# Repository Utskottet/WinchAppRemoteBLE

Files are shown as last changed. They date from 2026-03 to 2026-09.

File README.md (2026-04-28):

# ParaWinch

Paragliding winch control system. The winch controller communicates with a handheld remote over 868 MHz LoRa. The remote also connects via BLE to a phone app for monitoring and configuration.

**Phone app:** https://utskottet.github.io/parawinch/

## Repository structure

| Folder | Description | Hardware |
|---|---|---|
| `winch/` | Winch controller firmware | M5Stack Core (ESP32) + Waveshare LoRa 868 MHz |
| `remote/` | Handheld remote firmware | Seeed XIAO nRF52840 + Wio SX1262 |
| `sim/` | LoRa simulator — mimics winch transmissions for development without the winch | Seeed XIAO nRF52840 + Wio SX1262 |
| `archive/itsy-bitsy/` | Old test firmware, not in use | Adafruit ItsyBitsy |
| `docs/` | System specifications and notes | — |

## Communication

```
Phone  <── BLE ──>  Remote (Xiao nRF52840)  <── 868 MHz LoRa ──>  Winch (M5Stack ESP32)
```

## Docs

- [Specifications](docs/specifications.md)
- [Upgrade plan](docs/upgrade_plan.md)
- [Force calibration plan](docs/winch_force_calibration_plan.md)
- [Antenna tests](docs/antenna_tests.md)
- [Lisp scripts](docs/lisp.txt)

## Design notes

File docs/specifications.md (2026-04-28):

# Winch System Specifications
# Status: verified measured values only -- no estimates, no future plans

---

## Battery

| Parameter | Value | Source |
|---|---|---|
| Cell configuration | 20S | VESC config + log confirmed |
| Max voltage | 84.0 V | 20S × 4.2 V/cell |
| Nominal voltage | 74.0 V | 20S × 3.7 V/cell |
| Log resting voltage | 76.7 V | 3.835 V/cell (partial charge) |

Note: plan document says 22S -- this is wrong. Use 20S.

---

## Motor

| Parameter | Value | Source |
|---|---|---|
| Model | QS138 90H | plate |
| Serial | SIA72V4000WM11021 | plate |
| Pole pairs | 5 | user count + VESC detection + RPM measurement test confirmed 2026-04-27 |
| Flux linkage λ | 19.844 mWb | VESC motor detection |
| Motor R | 4 mΩ | VESC motor detection |
| Motor L | 35.3 µH | VESC motor detection |
| Kt | 0.1719 Nm/A | derived from λ, pole pairs |
| Kv (line-line peak) | 55.6 rpm/V | derived from λ, pole pairs |
| Kv (ERPM/V) | 277 ERPM/V | derived from λ via Kt (reliable); earlier ~257 value was from low-speed log with RPM controller error -- discard |
| Sensor mode | Hall | VESC config |

---

## Drivetrain

| Parameter | Value | Source |
|---|---|---|
| Drive type | Timing belt (synchronous) | physical |
| Belt | Optibelt Omega 1000-8M-20 | physical |
| Belt pitch | 8M (8 mm)  | physical |
| Belt length | 1000 mm (125 teeth) | physical |
| Belt width | 20 mm | physical |
| Belt material | Rubber, fiberglass cord | datasheet |
| Belt temp range | −30°C to +100°C | datasheet (ISO 9563) |
| Motor pulley | 22T | physical count  |
| Drum pulley | 90T | physical count  |
| Gear ratio | 4.091 | physical count 22T/90T confirmed (22/90 = 4.0909) |

Note: plan document says 4.09 -- that was correct. VESC was configured to 4.180 -- this is wrong, corrected to 4.091.

---

## Drum

| Parameter | Value | Source |
|---|---|---|
| Aluminium flange OD | 315 mm  | measured (structural reference, not used in force model) |
| Full drum diameter (all 1500m wound) | 265 mm | measured |
| Empty drum diameter (all line out) | 120 mm | measured |
| Estimated drum width | ~214 mm | derived from geometry |
| Estimated layers | 29 | derived |
| Turns per layer | ~85 | derived |

---

## Line

| Parameter | Value | Source |
|---|---|---|
| Type | Dyneema SK75 | physical |
| Diameter | 2.5 mm | measured |
| Total length | 1500 m | measured |
| Breaking strength | 740 kg | spec SK75 2.5mm |

---

## VESC

| Parameter | Value | Source / Note |
|---|---|---|
| VESC ID | 56 | from log |
| Wheel diameter (set) | 265 mm | corrected to full drum diameter |
| Gear ratio (set) | 4.091 | corrected from 4.180 |
| Battery cells (set) | 20S | correct |
| Motor current max | 80 A | currently set |
| Absolute max current | 388.7 A | hardware protection, do not change |
| Battery current max | 250 A | ~19 kW peak battery protection |
| ERPM max | 11000 | currently set |
| ERPM min | -11000 | symmetric |
| Current Kp | 0.0353 | VESC detection |
| Current Ki | 3.97 | VESC detection |
| Observer gain | 2.54 | VESC detection |

---

## Force Model

### Theoretical (from Kt, no losses)

```
line_force_kg = (Kt × current_A × gear_ratio) / (drum_radius_m × 9.81)
             = 0.5410 × current_A  (at full drum 265mm, gear ratio 4.091)
```

### Measured calibration (from static crane scale tests, full drum 265mm)

Drivetrain efficiency: 93% with ~4.6 kg constant friction offset.

```
force_kg = 0.503 × current_A − 4.6   (at full drum 265mm)
```

Source: log 2 (20–80A) and log 3 (100–140A), 2026-04-27.

| Current | Theoretical | Measured | Fit | Data quality |
|---|---|---|---|---|
| 20 A | 10.8 kg | 7.0 kg | 5.5 kg | measured |
| 40 A | 21.6 kg | 15.0 kg  | 15.5 kg | measured |
| 50 A | 27.1 kg | 20.0 kg  | 20.6 kg | measured |
| 60 A | 32.5 kg | 25.0 kg  | 25.6 kg | measured |
| 70 A | 37.9 kg | 30.0 kg  | 30.6 kg | measured |
| 80 A | 43.3 kg | 33.0 kg  | 35.7 kg | measured |
| 100 A | 54.1 kg | 50.0 kg  | 45.7 kg | measured |
| 120 A | 64.9 kg | --- | 55.8 kg | UNCERTAIN (43-56 kg range, repeat needed) |
| 140 A | 75.7 kg | 65.0 kg  | 65.8 kg | measured |

### Drum compensation (from measured calibration)

```
force_at_D = force_at_265mm × (265 / D_mm)
```

| Current | Full 265mm | 220mm  | 180mm  | 140mm | Empty 120mm |
|---|---|---|---|---|---|
| 40 A | 15.5 kg | 18.7 kg | 22.9 kg | 29.4 kg | 34.3 kg |
| 60 A | 25.6 kg | 30.8 kg | 37.7 kg | 48.4 kg | 56.5 kg |
| 80 A | 35.7 kg | 42.9 kg | 52.5 kg | 67.5 kg | 78.7 kg |
| 100 A | 45.7 kg | 55.1 kg | 67.3 kg | 86.5 kg | 101 kg |
| 120 A | 55.8 kg | 67.2 kg | 82.1 kg | 106 kg  | 123 kg |
| 140 A | 65.8 kg | 79.3 kg | 96.9 kg | 125 kg  | **145 kg** |

140A at empty drum = 145 kg. Safety factor vs 740 kg line = 5.1:1.

WARNING: In real tow operation the drum STARTS near-empty and fills during the tow.
The empty drum column is therefore the START of the tow, not the end.
Drum compensation is mandatory -- without it, current must be set based on the starting
(smallest) drum diameter to avoid overloading the pilot at the beginning of the tow.

---

## Drum Diameter vs Line-Out Model

Linear approximation (area model):

```
line_on_drum_m = 1500 - line_out_m
drum_radius_m  = sqrt(r_empty^2 + (r_full^2 - r_empty^2) × (line_on_drum / 1500))
drum_diam_mm   = drum_radius_m × 2 × 1000

where:
  r_empty = 0.060 m
  r_full  = 0.1325 m
```

Key points:

| Line out (m) | Line on drum (m) | Est. drum diam (mm) |
|---|---|---|
| 0 | 1500 | 265 |
| 300 | 1200 | 246 |
| 600 | 900 | 226 |
| 900 | 600 | 201 |
| 1200 | 300 | 169 |
| 1380 | 120 | 139 |
| 1500 | 0 | 120 |

---

## Line Speed (current ERPM max = 11000)

Motor mech RPM max = 11000 / 5 = 2200 RPM
Drum RPM max = 2200 / 4.091 = 538 RPM

| Drum state | Diam | Max line speed |
|---|---|---|
| Full (all wound) | 265 mm | 7.47 m/s = 27 km/h  |
| Empty (all out)  | 120 mm | 3.39 m/s = 12 km/h  |

27 km/h is below B class trim speed (~40 km/h). See upgrade_plan.md for ERPM and gear change plans.

Physics ceiling (back-EMF = battery voltage, regardless of ERPM setting):
- At resting 76.7V:  277 × 76.7 / 5 / 4.091 × π × 0.265 / 60 × 3.6 = 52 km/h at full drum
- At full charge 84V: 277 × 84   / 5 / 4.091 × π × 0.265 / 60 × 3.6 = 57 km/h at full drum

---

## Tow Operation Profile

### Direction of operation -- READ THIS FIRST

This is a REELING IN system, like a sailplane winch.

```
BEFORE TOW: line is laid out on the field. Drum is nearly EMPTY.
DURING TOW: winch reels IN the line. Drum FILLS.
AT RELEASE: pilot is airborne. Drum is approximately half full.
```

Typical tow range:
- Start: 1300–1500 m line out (drum 120–148 mm, nearly empty)
- Release: 600–750 m line out (drum 207–219 mm, about half full)

The MOST DANGEROUS moment is the START of the tow:
- Drum is at its smallest → highest force per amp
- Line speed is at its lowest (slow ground run)
- Pilot is on the ground and cannot escape

Safe current limits MUST be calculated from the starting drum diameter.
Setting current based on full drum (265 mm) will severely overload the pilot.

### Tow profile table (current ERPM 11000, 80 kg pilot)

Tow progresses top to bottom (line reeling in, drum filling):

| Phase | Line out | Drum | Max speed | 60 A  | 80 A  | 100 A | Max A (80 kg) |
|---|---|---|---|---|---|---|---|
| START | 1500 m | 120 mm | 12 km/h | 47 kg | 79 kg | **101 kg**| **81 A** |
| | 1400 m | 135 mm | 14 km/h | 42 kg | 70 kg | **90 kg** | **90 A** |
| | 1300 m | 148 mm | 15 km/h | 38 kg | 64 kg | **82 kg** | **98 A** |
| | 1200 m | 160 mm | 16 km/h | 35 kg | 59 kg | 76 kg | 105 A |
| | 1100 m | 171 mm | 17 km/h | 33 kg | 55 kg | 71 kg | 112 A |
| | 1000 m | 182 mm | 18 km/h | 31 kg | 52 kg | 67 kg | 118 A |
| | 900 m | 192 mm | 19 km/h | 30 kg | 49 kg | 63 kg | 124 A |
| | 800 m | 201 mm | 20 km/h | 28 kg | 47 kg | 60 kg | 130 A |
| | 700 m | 210 mm | 21 km/h | 27 kg | 45 kg | 58 kg | 136 A |
| RELEASE | 600 m | 219 mm | 22 km/h | 26 kg | 43 kg | 55 kg | 141 A |

Bold = exceeds 80 kg pilot weight limit at that current.

Force formula: force_at_D = (0.503 × A − 4.6) × (265 / D_mm)
Max safe A:    I_max = (target_kg × D_mm / 265 + 4.6) / 0.503

### Safe current limits by start position (80 kg pilot, force ≤ pilot weight)

| Start position | Drum diam | Max safe current |
|---|---|---|
| 1500 m out | 120 mm | 81 A |
| 1400 m out | 135 mm | 90 A |
| 1300 m out | 148 mm | 98 A |
| 1200 m out | 160 mm | 105 A |
| 1000 m out | 182 mm | 118 A |

As the tow progresses and the drum fills, the same current delivers progressively LESS force.
A tow started at 95 A from 1300 m delivers ~79 kg at the start and only ~55 kg at 600 m release.
This is the correct safe direction -- tension reduces as speed and altitude build.

### Why drum compensation matters

Without compensation, the operator must choose one fixed current for the whole tow.
That current is limited by the start condition (smallest drum = highest force).
With drum compensation in Lisp, current can be increased as the drum fills to maintain
a roughly constant force throughout the tow, allowing stronger pulls at mid-tow
without overloading the pilot at the start.

---

## Safety Analysis

### Line breaking strength vs motor current

Dyneema SK75 2.5mm breaks at 740 kg.

| Safety factor | Max working load | Current needed at full drum |
|---|---|---|
| 3:1 | 247 kg | 446 A |
| 4:1 | 185 kg | 335 A |
| 5:1 | 148 kg | 268 A |

The line will not break from motor force at any realistic operating current.
The risk is pilot overload, not line break.

### Current safety at VESC motor max (80 A)

| Drum state | Line pull | Safety factor vs line break |
|---|---|---|
| Full 265mm | 44 kg | 16.7:1 |
| Empty 120mm | 98 kg | 7.6:1 |

### Pilot load limits

Safe tow force for paraglider launch is typically 50-100% of pilot all-up weight.
This system is set up for 80 kg all-up pilot weight (body + harness + gear).
Max tow force target: 80 kg (= pilot weight).

Safe current at tow start depends on how much line is out -- see Tow Operation Profile above.
Do NOT use the full-drum force numbers to set operating current for real tows.

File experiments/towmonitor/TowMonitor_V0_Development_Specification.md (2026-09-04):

# TowMonitor V0
## Development & Prototype Specification

**Revision:** 0.1  
**Date:** 18 August 2026  
**Status:** Prototype definition / parts selected  

## 1. Purpose

TowMonitor V0 is a compact battery-powered sensor package for development of the next-generation paraglider tow system.

The unit combines tow-force measurement with flight-state sensing in one nRF52840-based node.

### Primary measurements

- Tow-line tension
- Airspeed
- Barometric altitude
- Vertical speed / vario
- Acceleration
- Angular motion / orientation

### Communications

- **V0:** Bluetooth Low Energy
- **Later:** 868 MHz LoRa using an SX1262 module

---

## 2. System Architecture

```text
WH-C100 load cell
      |
      v
Adafruit NAU7802
      |
      +------------------+
                         |
Adafruit BMP581 ---------+---- I2C ---- XIAO nRF52840 Sense
                         |
Sensirion SDP810 --------+
      |
      v
Pitot / static tubing

XIAO nRF52840 Sense
  |- nRF52840
  |- BLE
  |- onboard 6-axis IMU
  |- USB-C
  `- 1S LiPo charging
```

External digital sensors share:

```text
3V3
GND
SDA
SCL
```

The load-cell bridge connects locally to the NAU7802.

---

## 3. Selected Hardware

| Function | Selected part | Interface | Prototype form | Status |
|---|---|---|---|---|
| MCU / BLE | Seeed XIAO nRF52840 Sense | I2C / BLE / GPIO | Development board | Selected |
| IMU | Onboard XIAO 6-axis IMU | Internal | Integrated | Selected |
| Force sensor | WH-C100 150 kg internal load cell | 4-wire bridge | Bare extracted cell | Selected / characterize |
| Load-cell ADC | Adafruit NAU7802 STEMMA QT | I2C | Breakout + screw terminal | Selected |
| Vario / altitude | Adafruit BMP581 STEMMA QT | I2C | Breakout | Selected |
| Airspeed | Sensirion SDP810-500Pa | I2C | Through-hole sensor | Selected |
| Pitot plumbing | Pitot/static probe + silicone tube | Pressure | External | To select |
| Battery | Protected 1S LiPo ~500 mAh | Battery | Pouch cell | Target |
| Long-range radio | SX1262 868 MHz module | SPI | Module | Deferred |

---

## 4. Component Notes

### 4.1 XIAO nRF52840 Sense

Selected as the main controller because it combines:

- nRF52840 MCU
- BLE
- onboard 6-axis IMU
- USB-C
- LiPo charging
- enough GPIO for later SX1262 LoRa

The three external digital sensors all share the same I2C bus, so the sensor package uses very few MCU pins.

### 4.2 WH-C100 Load Cell + NAU7802

The lightweight load cell is extracted from a WH-C100 150 kg hanging scale.

Prototype work:

1. Identify the four bridge wires.
2. Connect to NAU7802.
3. Determine zero offset.
4. Calibrate against known loads.
5. Measure repeatability and creep.
6. Verify dynamic response.
7. Check temperature drift.

Mechanical mounting must load the cell in its intended axis without significant bending or side-loading.

### 4.3 BMP581 Vario / Altitude

The Adafruit BMP581 breakout is selected for easy STEMMA QT / Qwiic wiring.

Firmware will calculate:

- pressure
- altitude
- filtered vertical speed

The sensor should sample static ambient pressure and must be protected from direct ram airflow.

### 4.4 SDP810-500Pa Airspeed Sensor

Selected instead of the tiny SDP31 for the prototype because the SDP810 has mechanically useful tube connections while retaining high sensitivity at low differential pressure.

Key characteristics:

- differential pressure range: **±500 Pa**
- digital I2C interface
- proper tubing connections
- through-hole mounting
- suitable for pitot/static airspeed measurement

Connection:

```text
Pitot total pressure ---- SDP810 high-pressure port
Static pressure --------- SDP810 low-pressure port
```

Use short flexible silicone tubes and provide strain relief.

---

## 5. Electrical Prototype

V0 should be hand-wired on a small perfboard or carrier plate.

### Shared I2C bus

```text
XIAO 3V3 ----+---- NAU7802
             +---- BMP581
             `---- SDP810

XIAO GND ----+---- NAU7802
             +---- BMP581
             `---- SDP810

XIAO SDA ----+---- NAU7802
             +---- BMP581
             `---- SDP810

XIAO SCL ----+---- NAU7802
             +---- BMP581
             `---- SDP810
```

The NAU7802 and BMP581 can use STEMMA QT cables.

The SDP810 can simply use four soldered wires:

- VDD
- GND
- SDA
- SCL

### Battery

Target prototype battery:

**Protected 1S LiPo, approximately 500 mAh**

Charge through the XIAO USB-C interface.

---

## 6. Firmware Data Model

Minimum V0 telemetry:

```text
force_N
force_kgf

differential_pressure_Pa
airspeed_mps

barometric_pressure_Pa
altitude_m
vario_mps

accelerometer_x
accelerometer_y
accelerometer_z

gyro_x
gyro_y
gyro_z

battery_voltage

sensor_status
fault_flags
```

All sensor values should be timestamped so force, airspeed, vario and IMU data can later be correlated.

---

## 7. Prototype Development Sequence

### V0.1 — Bench assembly

Connect:

- XIAO
- NAU7802
- BMP581
- SDP810
- LiPo

Confirm all I2C devices operate together.

### V0.2 — Load-cell characterization

- Extract WH-C100 load cell
- identify bridge wiring
- tare
- calibrate against known loads
- test repeatability and dynamic response

### V0.3 — Vario

Implement:

- pressure acquisition
- pressure filtering
- altitude calculation
- vertical-speed calculation

### V0.4 — Airspeed

Install pitot/static probe and tubing.

Implement:

- differential pressure zeroing
- pressure filtering
- airspeed calculation
- calibration against a known/reference speed

### V0.5 — Combined telemetry

Combine and timestamp:

- force
- airspeed
- altitude
- vario
- IMU
- battery voltage

Send over BLE.

### V0.6 — Mechanical packaging

Provide:

- tube strain relief
- static-pressure protection
- load-cell mechanical alignment
- battery retention
- sensor enclosure

### V0.7 — Tow / flight testing

Compare recorded data against expected tow behaviour and tune filtering.

### V1 — Custom PCB

Only after V0 works reliably:

- integrate bare sensor ICs where useful
- reduce wiring
- add SX1262 868 MHz LoRa
- optimize battery monitoring
- optimize enclosure and connectors

---

## 8. Deferred / Open Items

- Exact pitot/static probe geometry
- Exact silicone-tube dimensions
- Exact LiPo capacity
- LoRa module and antenna implementation
- Final enclosure
- Whether NAU7802 and BMP581 remain as modules or become bare ICs on V1 PCB
- Characterization of the WH-C100 internal load cell

---

## 9. V0 Summary

The intended first prototype is:

```text
XIAO nRF52840 Sense
+
Adafruit NAU7802
+
WH-C100 load cell
+
Adafruit BMP581
+
Sensirion SDP810-500Pa
+
pitot/static probe
+
1S ~500 mAh LiPo
```

This gives one compact sensor node measuring:

**tow force + airspeed + altitude + vario + acceleration + angular motion**

without requiring a custom PCB for the first development version.

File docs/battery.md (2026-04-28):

# ParaWinch Battery Pack

## Overview

| Parameter | Value |
|---|---|
| Configuration | 20s8p (4 modules × 10s, 8 cells per group) |
| Total cells | 160 (40 per module) |
| Cell | LG INR18650 MH1 |
| Nominal voltage | 72V (3.6V × 20) |
| Max charge voltage | 84V (4.2V × 20) |
| Nominal capacity | 25.6 Ah (3200mAh × 8p) |
| Nominal energy | ~1844 Wh |
| Max continuous discharge | 80A (10A × 8p) |
| Charger | 84V 10A |

## Cell Specifications — LG INR18650 MH1

| Parameter | Value |
|---|---|
| Chemistry | INR (Li-NiMnCo) |
| Nominal capacity | 3200 mAh (min 3100 mAh) |
| Nominal voltage | 3.67V |
| Max charge voltage | 4.20V ± 0.05V |
| Cutoff voltage | 2.5V |
| Standard charge | CC 0.5C (1550 mA) / CV 4.2V / cutoff 50 mA |
| Max charge current | 1C (3100 mA) |
| Max discharge current | 10A continuous |
| Size | ø18.4 × 65.1 mm |
| Weight | 49 g |
| Datasheet | LG PS-CY-INR18650MH1 |

Compatible replacement: LG INR18650 MJ1 (3500 mAh, 10A) — same form factor, slightly higher capacity.

## Pack Structure

Four modules connected in series. Each module is 10s with 8 cells per series group (8p). Total: 20s8p, 160 cells.

```
[Module 1] — [Module 2] — [Module 3] — [Module 4]
  10s×8p       10s×8p       10s×8p       10s×8p
  40 cells     40 cells     40 cells     40 cells
```

Each module has balance taps at every series group. Nickel strip welded, 0.3 mm strip on series connections, 0.15 mm acceptable for parallel connections within groups.

### Module 3 — Cell Group Layout

Tap numbers visible on pack:
- Top side: + − 2 4 6 8
- Bottom side: 1 3 5 7 9

Series groups numbered 1–10 from − to +. Each group is 8p (4 cells visible on top side, 4 on bottom side). Adjacent groups share nickel strips at the series boundary.

## BMS

### Hardware
- Ant BMS 10S-24S, Double PCBA variant
- Product page: https://antbms.vip/product/ant-bms-10s-24s-50a-180a-smart-32v-88v-lifepo4-li-ion-lto-battery-protection-board-double-pcba/
- Balance method: Passive, 100 mA
- Balance connector: 21 wires (B0–B20), JST-type connector
- Current sense shunt range: 440A
- Bluetooth built-in (Android/iOS app)
- App: "ANT BMS" — tabs: State, Parameter, Set, BMS Control, Mine
- Admin password: unknown (default passwords 123456/000000/888888/666666 did not work)

### Operating Mode
- Charge-only configuration — BMS does not disconnect on discharge
- Discharge path bypasses BMS entirely — no undervoltage protection during discharge

### Configured Settings (2026-04-28)

| Setting | Value | Notes |
|---|---|---|
| Battery type | Li-ion | |
| Cell count | 20s | |
| Pack capacity | 26 Ah | 8p × 3.2Ah |
| Unit overvoltage protection | 4.20V | Cuts charge |
| Unit overvoltage recovery | 4.15V | Resumes charge |
| Lv2 unit overvoltage protection | 4.30V | Emergency backup |
| Lv2 unit overvoltage recovery | 4.20V | |
| Total overvoltage protection | 84.0V | Was 103V default! |
| Unit diff protection | 1.0V | Temporarily raised from 0.03V to clear fault — set back to 0.03V once cells balanced |
| Unit diff recovery | 0.020V | |
| Balance start voltage | 4.05V | |
| Charge unit balance start voltage | 4.05V | Was 4.10V default |
| Unit diff on voltage | 0.020V | |
| Charge overcurrent protection | 15A | Charger is 10A |
| Charge high temp protection | 45°C | Per MH1 datasheet |
| Charge high temp recovery | 40°C | |
| MOSFET high temp protection | 75°C | Default, leave as is |

### BMS Limitations Discovered

- Passive balance at 100 mA cannot close large voltage gaps (>200 mV) without overheating the balance circuit (reached 59°C)
- BMS latches "unit diff protection" fault when cell difference exceeds threshold — does not auto-clear on parameter change, requires power cycle or clearing protection log
- "Balance limit" warning blocks balancing when gap is too large — BMS treats it as fault, not a condition to fix
- In charge-only mode, balancing may only activate when charger is connected
- To clear stuck fault: use "clear protect time" in BMS Control tab, or power cycle BMS
- Factory default settings are dangerously permissive (total OVP at 103V, unit diff at 1V, charge OC at 50A)

## Protection & Power Path

- 500A KILOVAC LEV200 contactor
- Precharge: 100Ω 25W resistor (permanent passive snubber)
- 300A ANL fuse
- QS10 connectors

## Incident Log

### 2026-04-28 — Module 3 Group 10 Failure (Overcharge)

**Root cause:** Module 4 positive power lead was disconnected (missed during previous maintenance). BMS balance leads for all 20s were still connected. Charger pushed 20s charge voltage (84V) through only 15 series groups (modules 1+2+3). This resulted in approximately 5.6V per cell — far above the 4.2V maximum.

**Failure:** 4 of 8 cells in group 10 of module 3 (between tap 9 and + terminal) were destroyed. All 4 dead cells read 0V — internal short from severe overcharge. The remaining 4 cells in the group survived but were pulled to a lower voltage (~3.5V) by the dead cells.

**Diagnosis steps:**
1. Full pack + to − read 0V
2. Modules 1, 2, 4 verified healthy
3. Module 3: groups 1–9 all reading 4.0V per group (36V total from − to 9)
4. Group 10 (9 to +): 0V
5. Removed nickel strip on + side of group 10
6. All 4 cells in the dead half read 0V — confirmed destroyed

**Repair:**
- Replaced 4 dead cells with new LG INR18650 MH1 (sourced from Electrokit, 54 SEK/cell)
- New cells arrived at ~3.6–3.7V storage voltage
- Old 0.3 mm nickel strip reused for series connection to group 9
- New 0.15 mm nickel strip for parallel connections within the replacement group
- Spot weld settings: 9 ms pulse at 7.5V for 0.3 mm strip, 7 ms for 0.15 mm strip

**Post-repair state:**
- 19 groups at ~4.07V, group 10 at ~3.65V (average of 4 new cells at ~3.6V + 4 surviving cells at ~3.5V)
- BMS entered "unit diff protection" fault due to 400 mV gap
- BMS refused to charge or balance — fault latched
- Balance circuit overheated (59°C) attempting to close gap at 100 mA passive
- Resolution: external bench PSU charge of group 10 through balance connector pins (B19 and B20), 4.0V / 300 mA until group reaches ~3.9–4.0V, then BMS can handle remaining balance

**Key correction:** Pack is 20s8p (not 20s4p as initially assumed). Each group has 8 cells, not 4. The 4 replaced cells are paralleled with 4 surviving cells in group 10.

### Pre-Charge Safety Checklist

Before every charge:
- [ ] Physically verify all 4 module positive power leads are connected (tug test)
- [ ] Measure each module voltage across power terminals (not balance leads) — each should read ~40V
- [ ] Measure full string voltage across main power terminals — should be ~72–84V depending on SOC
- [ ] If full string reads ~60V (15s), a module power lead is disconnected — do not charge
- [ ] Check BMS app State tab — all 20 cells should show voltage, no fault flags

**Important:** Measuring full string voltage alone is NOT sufficient — BMS balance leads can show voltage from cells even when the power path is disconnected. Always verify power lead connections physically or measure across individual module power terminals.

### Post-Incident TODO

- [ ] External bench PSU charge group 10 to ~4.0V via balance pins B19/B20
- [ ] Reconnect BMS and verify fault clears
- [ ] Set unit diff protect back to 0.03V once cells balanced
- [ ] First full charge: monitor cell temps and BMS balance status
- [ ] Capacity test module 3 vs modules 1/2/4 — overcharged groups may have reduced cycle life
- [ ] Consider ordering 4 more MH1 cells as spares

## Supplier Notes

| Part | Source | Notes |
|---|---|---|
| LG INR18650 MH1 | Electrokit (SE) | 54 SEK incl. VAT, in stock |
| LG INR18650 MH1 | Nkon.nl | Alternative, fast EU shipping |
| 0.15 mm nickel strip | — | Sufficient for 8p at 10A/cell |
| 0.3 mm nickel strip | — | Use for series connections, harder to spot weld (needs 9ms+) |
| Ant BMS 10S-24S | antbms.vip | $59–90 USD depending on current rating |

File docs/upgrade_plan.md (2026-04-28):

# Winch Upgrade Plan
# Status: planning only -- nothing here is implemented on the real system

All numbers in this document are derived from real calibration data in specifications.md
but applied to configurations that do not yet exist on the machine.

---

## Open Items

### Completed 2026-04-27
- [x] Crane scale static pull test -- log 2 (20-80A) and log 3 (20-140A) done
- [x] Correct VESC wheel diameter from 280 mm to 265 mm
- [x] Correct VESC gear ratio from 4.180 to 4.091
- [x] VESC motor current max / abs max / battery max confirmed
- [x] VESC ERPM max / min confirmed
- [x] Confirm gear ratio -- 22T/90T = 4.091 physically counted and verified by RPM test
- [x] Confirm pole pairs = 5 by RPM measurement test
- [x] Confirm Kv = 277 ERPM/V from flux linkage (reliable); discarded noisy 257 value

### Still open -- current hardware
- [ ] Repeat 120A crane scale test (43-56 kg range too wide, not reliable)
- [ ] Verify actual drum width (estimated 214 mm)
- [ ] Confirm line-out tracking method (VESC get-dist or encoder)
- [ ] Add MOSFET temp telemetry logging during real tows
- [ ] Implement drum diameter compensation in Lisp using line-out estimate -- HIGH PRIORITY:
      without compensation, fixed current significantly overloads pilot at tow start vs mid-tow

### Drum spacer (current gear, immediate improvement) -- IN PROGRESS
- [ ] 3D print cylindrical spacer: 120 mm bore → 185 mm OD
- [ ] Verify full drum still fits within flange (new full = 300 mm, flange OD = 315 mm -- 7.5 mm margin)
- [ ] Re-wind full 1500 m line onto drum with spacer installed
- [ ] Re-confirm full drum diameter measurement after winding (expect ~300 mm)
- [ ] Raise ERPM to 18000 after spacer is installed (do not raise on bare 120 mm drum)

### Live tow logging -- after spacer install
- [ ] Log real tows: ERPM, motor current, battery voltage, MOSFET temp, duty cycle
- [ ] Log speed and height (GPS or barometric)
- [ ] Verify estimated drum diameter matches line-out model
- [ ] Check MOSFET temps under sustained load -- add temp logging if not already active
- [ ] Use logs to validate or correct force model before implementing Lisp compensation

### Gear change for B class towing
- [ ] Laser-cut 50T drum pulley (8M pitch, ≥20mm wide, PC layers)
- [ ] Source replacement belt Optibelt Omega 840-8M-20 (105T)
- [ ] Fit 50T drum pulley, shift motor mount ~12mm, update VESC gear ratio to 2.273
- [ ] Re-calibrate force model with crane scale at 2.27:1 -- mandatory before any tows
- [ ] Raise VESC motor current max to ≥160A; verify MOSFET thermals in static tests first
- [ ] Set ERPM max ~20,000 for 2.27:1 ratio
- [ ] No-load ERPM test after gear change to verify Kv = 277 ERPM/V at new ratio

---

## ERPM Upgrade: 11000 → 18000 (current gear, B class prep)

At current gear ratio 4.091:1, raising ERPM to 18000 gives:

Motor mech RPM max = 18000 / 5 = 3600 RPM
Drum RPM max = 3600 / 4.091 = 880 RPM

| Drum state | Diam | Max line speed |
|---|---|---|
| Full (all wound) | 265 mm | 12.22 m/s = 44 km/h |
| Empty (all out)  | 120 mm |  5.53 m/s = 20 km/h |

Back-EMF at 18000 ERPM = 18000 / 277 = 65.0 V
Voltage headroom at resting 76.7 V = 11.7 V
Voltage headroom at full charge 84 V = 19 V

Still insufficient for B class at tow start (120mm drum, 20 km/h max) -- see gear change below.
Useful as interim improvement for shorter line starts (≥600m out) or A class gliders.

Tow profile at ERPM 18000, current gear 4.091:1, 80 kg pilot:

| Phase | Line out | Drum | Max speed | 60 A  | 80 A  | 100 A | Max A (80 kg) |
|---|---|---|---|---|---|---|---|
| START | 1500 m | 120 mm | 20 km/h | 47 kg | 79 kg | **101 kg**| **81 A** |
| | 1400 m | 135 mm | 22 km/h | 42 kg | 70 kg | **90 kg** | **90 A** |
| | 1300 m | 148 mm | 25 km/h | 38 kg | 64 kg | **82 kg** | **98 A** |
| | 1200 m | 160 mm | 27 km/h | 35 kg | 59 kg | 76 kg | 105 A |
| | 1100 m | 171 mm | 28 km/h | 33 kg | 55 kg | 71 kg | 112 A |
| | 1000 m | 182 mm | 30 km/h | 31 kg | 52 kg | 67 kg | 118 A |
| | 900 m | 192 mm | 32 km/h | 30 kg | 49 kg | 63 kg | 124 A |
| | 800 m | 201 mm | 33 km/h | 28 kg | 47 kg | 60 kg | 130 A |
| | 700 m | 210 mm | 35 km/h | 27 kg | 45 kg | 58 kg | 136 A |
| RELEASE | 600 m | 219 mm | 36 km/h | 26 kg | 43 kg | 55 kg | 141 A |

Force formula (unchanged from calibration): force_at_D = (0.503 × A − 4.6) × (265 / D_mm)

---

## Gear Change: 90T → 50T Drum Pulley (B Class Towing)

### Why the current gear is insufficient

At 4.091:1 and full charge 84V, physics ceiling at 1300m out (148mm drum):
```
Max ERPM (physics) = 277 × 84 = 23,268
Drum RPM = 23,268 / 5 / 4.091 = 1,138 RPM
Max speed = π × 0.148 × 1,138 / 60 = 8.84 m/s = 31.8 km/h
```
B class trim speed ≈ 40 km/h. 31.8 km/h is the absolute ceiling -- no ERPM setting can overcome this.

### Why flux weakening is not viable

VESC flux weakening currently disabled (field weakening current = 0A).
For 35% speed gain to reach ~43 km/h at 1300m out:
```
id = (19.844e-3 − 19.844e-3/1.35) / 35.3e-6 = 146 A d-axis
```
146A d-axis (heating only, no torque) is not practical. Motor and MOSFET would overheat.

### Tooth count analysis -- why 50T drum pulley

Back-EMF to reach 40 km/h at 120mm drum = 2872 / T_motor × (T_drum/90) volts.
With fixed 22T motor pulley, varying drum pulley:

```
| Drum teeth | Ratio  | Max speed 84V | Max speed 77V | I for 80kg start | 40 km/h? |
|------------|--------|---------------|---------------|------------------|----------|
| 90T (now)  | 4.09:1 | 26 km/h       | 24 km/h       |  81 A            | NO       |
| 60T        | 2.73:1 | 35 km/h       | 32 km/h       | 107 A            | NO       |
| 56T        | 2.55:1 | 37 km/h       | 34 km/h       | 114 A            | NO       |
| 50T        | 2.27:1 | 46 km/h       | 42 km/h       | 139 A            | YES      |
| 44T        | 2.00:1 | 52 km/h       | 48 km/h       | 158 A            | YES      |
```

50T is the recommended choice:
- Achieves 40+ km/h at 120mm drum on both full and resting charge
- 139A for 80 kg at tow start -- within VESC 100/250 capability
- 44T gives unnecessary speed at the cost of ~20A more current

### Practical implementation

**Drum pulley:** 50T, 8M pitch, ≥20mm wide, laser-cut PC layers (same method as current 90T).
Pitch diameter = 50 × 8 / π = 127.3mm (vs current 229.2mm).

**Belt:** smaller drum pulley requires shorter belt.
At current center distance ~262mm, belt length needed ≈ 816mm.
Use **Optibelt Omega 840-8M-20** (105T, 840mm).
Motor mount shifts ~12mm further from drum to tension correctly.

**VESC settings after change:**
- Gear ratio: 2.273 (50/22)
- ERPM max: ~20,000 (gives 40 km/h at 120mm drum, ~74 km/h at full 265mm drum -- but drum
  compensation in Lisp should limit actual speed at larger diameters)
- Motor current max: raise to ≥160A after static crane scale verification

### Estimated force model at 2.27:1

NOT measured. Extrapolated from 4.091:1 calibration assuming same efficiency and proportional friction.

```
Theoretical:       force_kg = 0.301 × A   (at full drum 265mm)
Estimated measured force_kg ≈ 0.280 × A − 2.56
```

**Re-calibrate with crane scale before any tows. Do not use these numbers operationally.**

Safe motor current for 80 kg pilot at tow start (120mm drum, estimated):
```
I ≈ 139 A
```
Raise VESC motor current max to ≥160A for margin. Verify MOSFET thermals in static tests.

---

## Drum Spacer: 120 mm → 185 mm Empty Drum (current gear 4.091:1)

### Why a spacer helps

Without spacer: empty drum = 120 mm, full drum = 265 mm.
Force and speed both vary 2.21× across the tow range.
Max safe current at tow start (120 mm drum, 80 kg pilot) = 81 A -- very low.

Adding a cylindrical spacer to the drum core raises the empty diameter.
If full drum is allowed to grow to 300 mm (flange OD = 315 mm, 7.5 mm margin), the same 1500 m
of line fits in the new annulus by conservation of cross-section area:

```
New annulus area = old annulus area
r_full_new² − r_empty_new² = r_full_old² − r_empty_old²
150² − r_empty_new² = 132.5² − 60²
r_empty_new = sqrt(22500 − 13956) = sqrt(8544) = 92.4 mm
→ D_empty_new = 185 mm
```

### Tow profile with spacer, ERPM 18000, 80 kg pilot

Drum diameter model (area model):
```
drum_radius_mm = sqrt(8543 + 13957 × line_on_drum_m / 1500)
```

| Phase | Line out | Drum | Max speed | 60 A  | 80 A  | 100 A | 120 A | Max A (80 kg) |
|---|---|---|---|---|---|---|---|---|
| START | 1500 m | 185 mm | 30.7 km/h | 37 kg | 51 kg | 65 kg | **80 kg** | **120 A** |
| | 1400 m | 195 mm | 32.3 km/h | 35 kg | 48 kg | 62 kg | 76 kg | 126 A |
| | 1300 m | 204 mm | 33.8 km/h | 33 kg | 46 kg | 59 kg | 72 kg | 132 A |
| | 1200 m | 213 mm | 35.3 km/h | 32 kg | 44 kg | 57 kg | 69 kg | 137 A |
| | 1100 m | 222 mm | 36.7 km/h | 31 kg | 43 kg | 55 kg | 67 kg | 142 A |
| | 1000 m | 230 mm | 38.1 km/h | 29 kg | 41 kg | 53 kg | 64 kg | 147 A |
| | 900 m | 238 mm | 39.4 km/h | 28 kg | 40 kg | 51 kg | 62 kg | 152 A |
| | 800 m | 245 mm | 40.7 km/h | 28 kg | 39 kg | 50 kg | 60 kg | 156 A |
| | 700 m | 253 mm | 42.0 km/h | 27 kg | 37 kg | 48 kg | 58 kg | 161 A |
| RELEASE | 600 m | 260 mm | 43.1 km/h | 26 kg | 36 kg | 47 kg | 57 kg | 165 A |

Force formula (unchanged): `force_at_D = (0.503 × A − 4.6) × (265 / D_mm)`

Physics ceiling at tow start (185 mm drum):
- At resting 76.7V: 277 × 76.7 / 5 / 4.091 × π × 0.185 / 60 × 3.6 = **36.2 km/h**
- At full charge 84V: 277 × 84   / 5 / 4.091 × π × 0.185 / 60 × 3.6 = **39.7 km/h**

ERPM 18000 gives 30.7 km/h at tow start -- below the physics ceiling, so ERPM is the binding limit
throughout the entire tow. Raising ERPM further (up to ~23,000 at 84V) would give more start speed.

### Comparison: without vs with spacer

| Metric | No spacer (120 mm) | Spacer (185 mm) |
|---|---|---|
| Start speed at ERPM 18000 | 20 km/h | 30.7 km/h |
| Physics ceiling at start (84V) | 26 km/h | 39.7 km/h |
| Max safe current at start (80 kg)| 81 A | 120 A |
| Force variation start→600m rel.  | 1.83× | 1.40× |

---

## Speed Ceiling Reference (current gear 4.091:1, all conditions)

```
| Battery   | Physics ceiling ERPM | Max speed full drum | Max speed 120mm drum |
|-----------|----------------------|---------------------|----------------------|
| 84V full  | 23,268               | 57 km/h             | 26 km/h              |
| 76.7V rest| 21,236               | 52 km/h             | 24 km/h              |
```

Setting ERPM above these values has no effect -- motor back-EMF prevents higher speed.

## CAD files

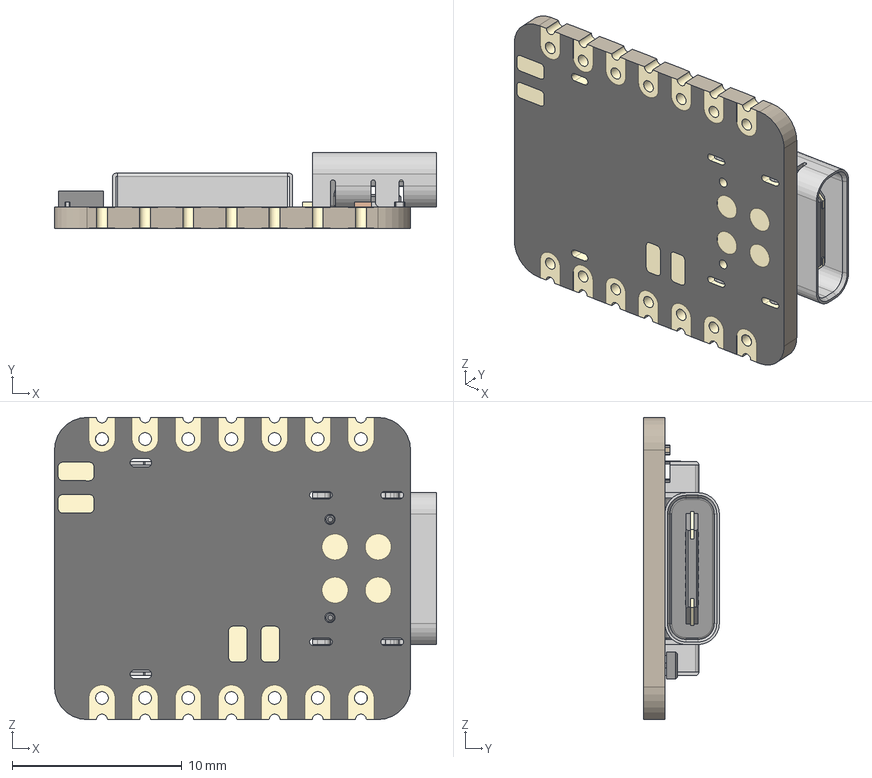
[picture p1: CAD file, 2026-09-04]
experiments/Fork Ikoka Nano/3dmodels/XIAO-nRF52840 v15.step
22.5 x 4.46 x 17.8 mm
BOSS-EXTRUDE14_8_
BOSS-EXTRUDE7_4_
BOSS-EXTRUDE7_3_
BOSS-EXTRUDE14_4_
BOSS-EXTRUDE14_2_
BOSS-EXTRUDE14_11_
BOSS-EXTRUDE7_7_
BOSS-EXTRUDE14_9_
BOSS-EXTRUDE14_3_
BOSS-EXTRUDE14_7_
MIRROR2
BOSS-EXTRUDE14_5_
BOSS-EXTRUDE14_12_
BOSS-EXTRUDE7_8_
BOSS-EXTRUDE7_1_
BOSS-EXTRUDE14_10_
BOSS-EXTRUDE7_9_
BOSS-EXTRUDE14_6_
BOSS-EXTRUDE14_1_
BOSS-EXTRUDE7_6_
BOSS-EXTRUDE7_2_
CUT-EXTRUDE5
BOSS-EXTRUDE7_5_
Shield
Pins
CAP x 2
ANT1
Silkscreen
CAP 3
LED
USR
2 v1

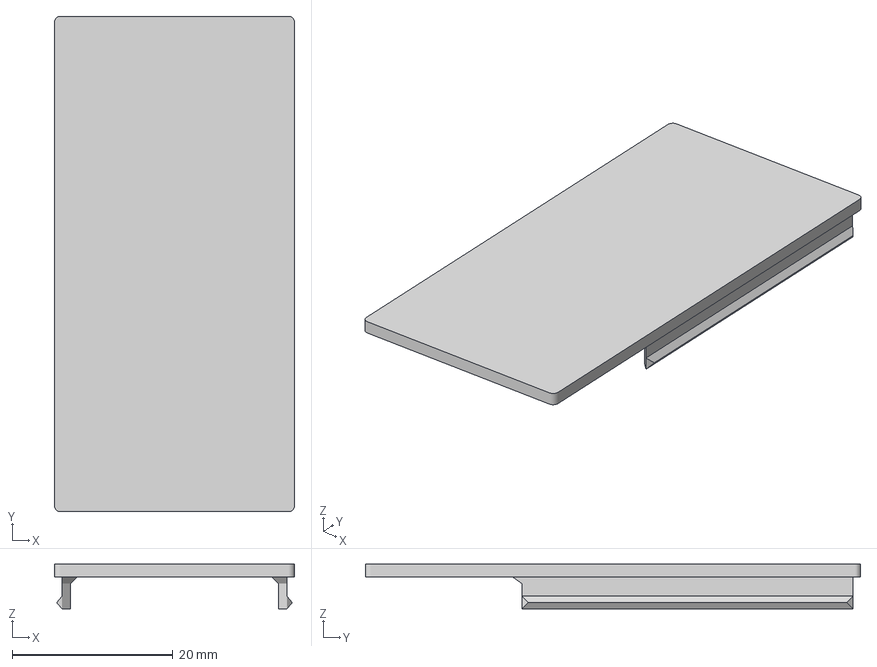
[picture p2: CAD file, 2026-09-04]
experiments/Fork Ikoka Nano/enclosure/ikoka nano enclosure lid.3mf
29.9 x 61.7 x 5.60 mm

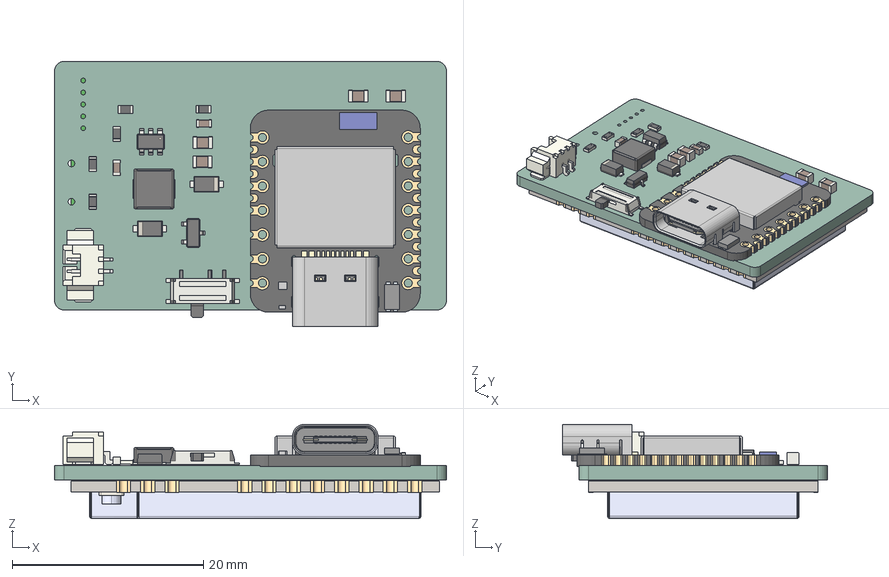
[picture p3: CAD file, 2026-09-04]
experiments/Fork Ikoka Nano/Fork Ikoka Nano.step
41.0 x 27.7 x 9.86 mm
C_0805_2012Metric x 4
R_0603_1608Metric x 5
L_Changjiang_FXL0420
L_APV_APH0420
C_0603_1608Metric x 2
Molex_53261_0271
D_SOD_123F x 2
Fusion_sp
SOT-23
BOSS-EXTRUDE14_8_
BOSS-EXTRUDE7_4_
BOSS-EXTRUDE7_3_
BOSS-EXTRUDE14_4_
BOSS-EXTRUDE14_2_
BOSS-EXTRUDE14_11_
BOSS-EXTRUDE7_7_
BOSS-EXTRUDE14_9_
BOSS-EXTRUDE14_3_
BOSS-EXTRUDE14_7_
MIRROR2
BOSS-EXTRUDE14_5_
BOSS-EXTRUDE14_12_
BOSS-EXTRUDE7_8_
BOSS-EXTRUDE7_1_
BOSS-EXTRUDE14_10_
BOSS-EXTRUDE7_9_
BOSS-EXTRUDE14_6_
BOSS-EXTRUDE14_1_
BOSS-EXTRUDE7_6_
BOSS-EXTRUDE7_2_
CUT-EXTRUDE5
BOSS-EXTRUDE7_5_
Shield
Pins
SOT-23-6
E22-900M30S
Fork Ikoka Nano_PCB

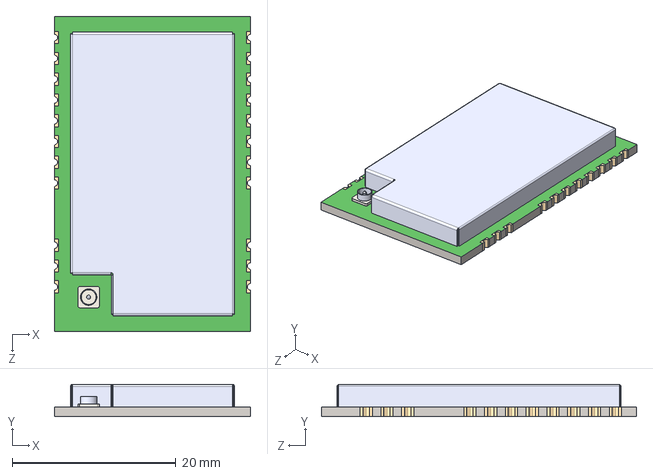
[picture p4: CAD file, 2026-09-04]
experiments/Fork Ikoka Nano/symbols/E22-900M30S/E22-900M30S.step
24.0 x 3.97 x 38.5 mm

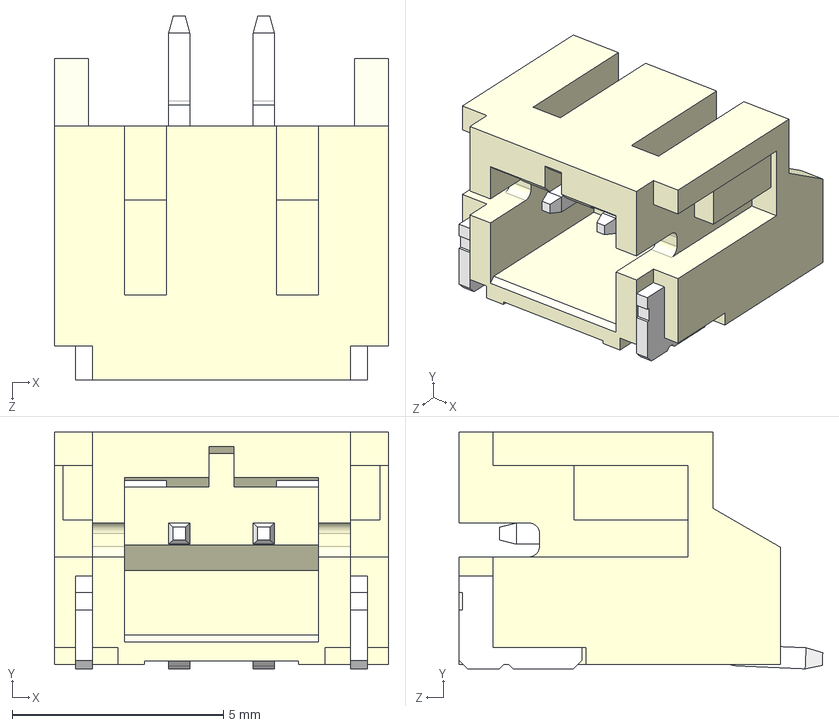
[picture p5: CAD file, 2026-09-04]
experiments/Fork Ikoka Nano/3dmodels/S2B-PH-SM4-TB--3DModel-STEP-269445.STEP
7.90 x 5.60 x 8.60 mm

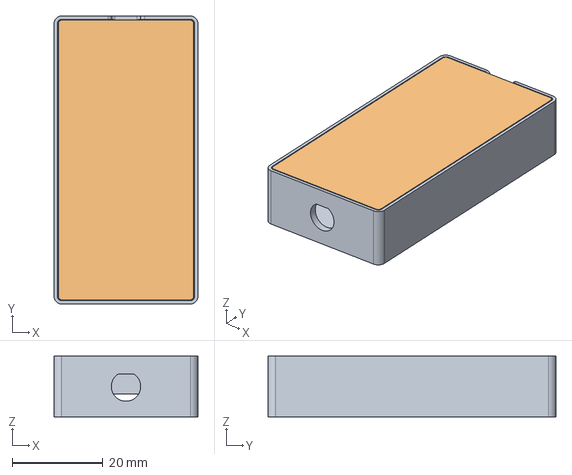
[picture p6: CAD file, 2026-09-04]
experiments/Fork Ikoka Nano/enclosure/ikoka nano enclosure.step
31.7 x 63.5 x 13.4 mm

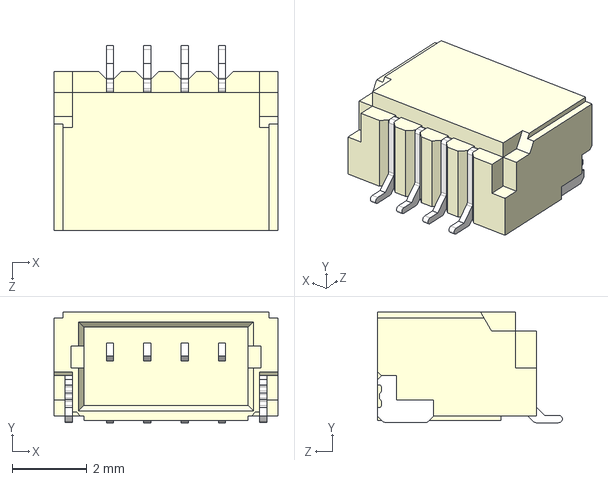
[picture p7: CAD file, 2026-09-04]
experiments/Fork Ikoka Nano/3dmodels/SM04B-SRSS-TB(LF)(SN)--3DModel-STEP-269445.STEP
6.00 x 2.96 x 4.95 mm

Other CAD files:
experiments/Fork Ikoka Nano/enclosure/ikoka nano enclosure lid.stl
experiments/Fork Ikoka Nano/enclosure/ikoka nano enclosure.3mf
experiments/Fork Ikoka Nano/enclosure/ikoka nano enclosure.f3d
experiments/Fork Ikoka Nano/enclosure/ikoka nano enclosure.stl

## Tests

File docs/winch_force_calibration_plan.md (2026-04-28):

# Paragliding Winch Force Calibration Plan

## Goal

Build a reliable calibration table/model for the electric paragliding winch so we understand:

- motor current → line pull
- drum diameter → force multiplication
- line-out amount → estimated drum diameter
- safe current limits for different tow settings
- safe state values in VESC Lisp
- what values the ESP32 should send over CAN
- what telemetry should be logged/verified

Final goal: a practical calculator/table that lets us set tow strength safely without needing to plug USB into the VESC and manually edit motor config or Lisp state values.

---

## Current System

### Hardware

- Motor: QS138 90H, 72 V / 4000 W family
- Motor plate marking / serial: `SIA72V4000WM11021`
- Battery: 22S
- VESC: VESC 100/250
- External drive ratio:
  - motor sprocket/pulley: 22T
  - drum sprocket/pulley: 90T
  - ratio = `90 / 22 = 4.09:1`
- Drum diameter:
  - full drum: 250 mm
  - empty drum/core: 120 mm
- Winch line length:
  - total line length: 1500 m
  - normal launch starts with about 800–1300 m line out
  - release usually happens in the air before the drum is empty
  - at release, remaining line on drum is often around half of the start amount
  - example: start with 800–1300 m out, release may happen after pulling in roughly 400–600 m

### Control

- ESP32 communicates with VESC over CAN.
- VESC has LispBM script running.
- ESP32 sends CAN state commands.
- Lisp receives state and calls `set-current`.
- Current Lisp maps states to fixed current values.
- Proposed improvement:
  - ESP32 sends one adjustable “max tow current” or “tow setting”
  - Lisp derives:
    - state 5 = max × 0.8
    - state 6 = max × 1.0
  - Lisp clamps all values before using them
  - VESC motor config remains the hard safety ceiling

---

## Important Realization

A fixed current does **not** mean fixed line pull.

Line pull changes directly with drum radius/diameter.

Same motor torque/current gives more pull on a smaller drum.

### Drum Force Ratio

```text
full drum diameter = 250 mm
empty drum diameter = 120 mm

force ratio = 250 / 120 = 2.083
```

So if a current gives 80 kg at full drum, it gives roughly:

```text
80 × 2.083 = 166.7 kg
```

at empty drum.

This is the main danger.

---

## Full Drum Calibration Question

Earlier estimate/measurement suggested:

```text
~140 A motor current ≈ ~80 kg line pull at full 250 mm drum
```

Independent motor/drivetrain sanity check using likely QS138 data:

```text
approx Kv = 4000 rpm / 72 V = 55.6 rpm/V
Kt ≈ 9.55 / 55.6 = 0.172 Nm/A

motor torque at 140 A:
140 × 0.172 = 24.1 Nm

drum torque:
24.1 × 4.09 = 98.6 Nm

full drum radius:
250 / 2 = 125 mm = 0.125 m

line force:
98.6 / 0.125 = 789 N

kg pull:
789 / 9.81 = 80.4 kg
```

So 140 A ≈ 80 kg at full drum is plausible.

But this must be verified with real load testing.

---

## Static Test Method

Available tool: crane scale.

This is enough for static calibration.

Setup:

```text
Winch line -> crane scale -> fixed rated anchor
```

Test should be done with:

- full drum first
- short pulls only
- no people in line with the rope
- rated anchor, shackles, straps, hooks
- remote operation / stand to the side
- start low and step upward

Suggested test points:

```text
40 A
60 A
80 A
100 A
120 A
140 A
```

Optional finer points later:

```text
50 A
70 A
90 A
110 A
130 A
150 A
```

For each point record:

```text
commanded current A
actual motor current A
battery current A
battery voltage V
ERPM
mechanical RPM if available
duty cycle %
MOSFET temp
motor temp
faults
crane scale peak kg
drum diameter mm
line-out estimate
ambient temperature
```

Important: crane scale peak value is useful, but avoid long static stalls.

---

## What Static Test Gives Us

Static test gives the real relationship:

```text
motor current -> line pull
```

for a known drum diameter.

This is enough to build a safe current table.

It does not fully prove dynamic towing force, but it gives the base torque/pull calibration.

---

## Dynamic Effects Not Fully Captured by Static Test

During real towing, additional factors matter:

- drum is rotating
- line speed changes
- pilot accelerates
- drum diameter changes continuously
- battery voltage sags
- VESC may become voltage/duty limited
- motor and MOSFET temperature rise
- line angle and friction may change
- tow release happens before drum is empty

Without a live load cell, dynamic pull must be calculated/estimated from motor current and drum diameter, not directly measured.

So the calculator can be very good, but it should still be validated conservatively in real use.

---

## Core Force Model

If we know line pull at full drum for a given current:

```text
pull_at_current_drum =
pull_at_full_drum × full_diameter / current_diameter
```

For current limiting:

```text
allowed_current =
full_drum_current × current_diameter / full_diameter
```

For this winch:

```text
allowed_current =
full_drum_current × current_diameter / 250
```

Example if 145 A is safe at full drum:

```text
250 mm drum -> 145 A
200 mm drum -> 116 A
160 mm drum -> 93 A
120 mm drum -> 70 A
```

---

## Required Calculator / Spreadsheet Tabs

### 1. Constants

```text
motor model
motor plate marking / serial
battery voltage / cells
gear ratio
full drum diameter
empty drum diameter
line length
line diameter
drum width if needed
VESC hard current limit
VESC battery current limit
VESC ERPM limit
state factors
safety margin
```

### 2. Static Pull Test Data

Columns:

```text
test number
date
drum diameter mm
line out m
commanded current A
actual motor current A
battery current A
battery voltage V
ERPM
duty %
MOSFET temp C
motor temp C
crane scale kg
notes
```

### 3. Calibration Curve

Use measured data to fit:

```text
pull_kg = a × current_A + b
```

or if better:

```text
pull_kg = a × current_A
```

Then compare measured vs predicted.

### 4. Drum Diameter / Line-Out Model

Need to estimate drum diameter based on line remaining on drum.

Known:

```text
total line length = 1500 m
start line out usually = 800–1300 m
release after pulling in roughly 400–600 m
full drum diameter = 250 mm
empty drum diameter = 120 mm
```

This tab estimates:

```text
line remaining on drum
current drum diameter
current drum radius
force multiplier
```

### 5. Current Limit Table

For each tow setting:

```text
target pull kg
equivalent full-drum current
current diameter
diameter compensation
allowed current
state 5 current = allowed × 0.8
state 6 current = allowed × 1.0
```

### 6. Dynamic Log

For later real tow logging:

```text
time
state
commanded current
actual motor current
battery current
battery voltage
ERPM
duty
estimated drum diameter
estimated line speed
estimated line pull
MOSFET temp
motor temp
faults
```

### 7. Safety Settings

List:

```text
VESC motor current max
VESC absolute max current
VESC battery current max
VESC ERPM max
Lisp max current clamp
CAN timeout behavior
max allowed temperature
max allowed duty
max allowed estimated pull
```

---

## ESP32 / Lisp Architecture

### ESP32 Should Handle

- user display
- pilot weight / tow class / max setting
- maybe convert UI value to target current
- send CAN command to VESC Lisp
- receive accepted value back
- show accepted value, not just requested value
- log telemetry if possible

### VESC Lisp Should Handle

- receive CAN state command
- receive max tow current or tow setting
- clamp received values
- derive state 5 and state 6
- ramp current
- timeout to safe state
- send accepted values back
- optionally apply drum compensation if diameter/line-out is available

### VESC Config Should Handle

Hard limits only:

```text
motor current max
battery current max
ERPM max
temperature limits
voltage limits
absolute max current
```

Do not rewrite VESC config during normal use.

---

## Proposed State Logic

Fixed lower states:

```text
state 0 = 0 A
state 1 = fixed low current
state 2 = fixed low/medium current
state 3 = fixed medium current
state 4 = fixed high-ish current
```

Variable high states:

```text
state 5 = max_tow_current × 0.8
state 6 = max_tow_current × 1.0
```

But `max_tow_current` must be compensated for drum diameter if we want constant line pull.

---

## Guardrails

Guardrails are checks that prevent bad input from becoming dangerous motor output.

Required:

```text
1. VESC config hard ceiling
2. Lisp clamps CAN values
3. Lisp accepts only valid states
4. Lisp timeout if ESP/CAN command disappears
5. Lisp ramps current changes
6. Lisp sends accepted max value back to ESP
7. ESP displays accepted value
8. telemetry verifies actual current / ERPM / temp
```

Example fault logic:

```text
CAN timeout -> state 0 / current 0
invalid state -> ignore or state 0
requested max current above clamp -> clamp down
actual current too high too long -> cut
ERPM too high -> reduce/cut
motor/MOSFET temp too high -> reduce/cut
```

---

## Key Open Questions / Data Still Needed

### From VESC Tool

Need to record:

```text
motor resistance
motor inductance
flux linkage / lambda
pole pairs
detected sensors / hall status
motor current max
absolute max current
battery current max
ERPM max
temperature limits
```

### During Static Test

Need to log:

```text
actual motor current
battery current
battery voltage
ERPM
duty
MOSFET temp
motor temp
faults
crane scale kg
drum diameter
```

### Mechanical / Line Model

Need:

```text
line diameter
drum width
how evenly the line winds
whether drum diameter can be estimated from line-out
whether get-dist is accurate enough
```

---

## Practical Next Step

1. Set up crane scale static test at full drum.
2. Test 40, 60, 80, 100, 120, 140 A.
3. Log VESC realtime values for each point.
4. Build first spreadsheet:
   - current vs kg at full drum
   - drum compensation
   - safe state 5/state 6 table
5. Then modify Lisp and ESP32:
   - ESP sends max tow/current setting
   - Lisp clamps and derives state 5/6
   - Lisp sends accepted value back
6. Later add drum diameter compensation using line-out estimate.

---

## Main Safety Conclusion

If full drum 140 A is around 80 kg, then the same 140 A at empty drum is roughly:

```text
80 × 250 / 120 = 166.7 kg
```

So fixed current states are unsafe across the full drum range.

The winch needs either:

```text
A) current compensation by drum diameter / line-out
```

or

```text
B) conservative current limits based on smallest drum diameter
```

or best:

```text
C) direct live load cell feedback
```

For now, with only a crane scale, static calibration + drum compensation is the practical route.

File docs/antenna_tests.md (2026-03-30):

# Antenna / Signal Tests — ParaWinch LoRa 868 MHz

**Setup:** Seeed XIAO nRF52840 + Wio SX1262 remote, ESP32 + Waveshare SX1262 winch
**RF params:** 868.1 MHz · SF9 · BW125 · CR4/6 · 22 dBm
**Sensitivity floor:** SX1262 @ SF9/BW125 ≈ −124 dBm
**Free-space path loss formula:** RSSI@distance = RSSI@10m − 20×log10(distance/10)

---

## Phase 1 — Finding the baseline (buggy firmware, XIAO sim as winch)

| # | Winch antenna | Remote antenna | Winch RSSI | Winch SNR | Remote RSSI | Remote SNR |
|---|---|---|---|---|---|---|
| 1 | PCB trace | ½ dipole | −80 dBm | 11 dB | −75 dBm | 11 dB |
| 2 | ¼ wave | ½ dipole | −90 dBm | 10.5 dB | −76 dBm | 11 dB |
| 3 | ½ dipole | ½ dipole | −77 dBm | 11.2 dB | −68 dBm | 10 dB |
| 4 | ½ dipole | ½ dipole + new IPEX | −81 dBm | 11 dB | −86 dBm | 10 dB |

All results ~30 dB below expected. Root cause unknown at this point.

---

## Phase 2 — Firmware fixes applied to both XIAO units

### Bug 1 — RF switch pin never driven (main culprit, ~30 dB loss)
`LORA_RXEN_PIN D5` defined in `utilities.h` but never passed to RadioLib.
Wio SX1262 has a physical RF switch on D5 (HIGH=RX, LOW=TX). With it floating the RX path was nearly dead.
**Fix:** `lora.setRfSwitchPins(LORA_RXEN_PIN, RADIOLIB_NC)` added to both XIAO firmwares.

### Bug 2 — OCP silently failing (secondary)
`LORA_CURRENT_LIMIT_MA 240.0f` exceeds RadioLib's 140 mA max. Call silently failed, leaving OCP at 60 mA.
SX1262 draws ~118 mA at 22 dBm — OCP tripped on every TX, reducing output power.
**Fix:** Changed to `140.0f` in both XIAO firmwares.

| # | Winch ant | Remote ant | Winch RSSI | Winch SNR | Remote RSSI | Remote SNR | Notes |
|---|---|---|---|---|---|---|---|
| 5 | ½ dipole | ½ dipole + new IPEX | −44 dBm | 10.8 dB | −40 dBm | 11 dB | 10 m |
| 6 | ½ dipole | ½ dipole + old IPEX | −33 dBm | 10.8 dB | −36 dBm | 11 dB | 10 m |

**+33 dB improvement on winch side. Numbers now in expected range.**
New IPEX on remote was bad (−18 dB). Reverted to old IPEX.

---

## Phase 3 — Real winch hardware (ESP32 + Waveshare SX1262)

**Hardware notes:**
- Waveshare SX1262 RF switch wired to DIO2 internally — no external pin needed
- Antenna: ½ dipole on 1 m coax, elevated 1 m, vertical polarisation
- Remote: ½ dipole, elevated 1.5 m, vertical polarisation
- Test environment: shop gate opening, large building behind = multipath present
- Stepper motor and driver close to winch SX1262

### OCP investigation

| # | OCP state | Winch RSSI | Winch SNR | Remote RSSI | Remote SNR | Stepper |
|---|---|---|---|---|---|---|
| 7 | not fixed (60 mA) | −42 dBm | 11 dB | −58 dBm | 11 dB | off |
| 8 | fixed (140 mA) | −60 dBm | 10 dB | −39 dBm | 10 dB | off |
| 9 | disabled/reverted | −45 dBm | 11 dB | −51 dBm | 11 dB | off |
| 10 | disabled | −51 dBm | 10.5 dB | −52 dBm | 11 dB | connected |

**Finding:** OCP fix at 140 mA causes supply rail desense on winch — PA current ripple couples into LNA.
Costs −15 dB on winch RX but gains +12 dB on winch TX. Waveshare module needs hardware decoupling caps to fix properly.
**Decision: OCP left disabled on winch. Command reception is safety-critical.**

### Distance tests — no BLDC, stepper connected

| # | Distance | Winch RSSI | Winch SNR | Remote RSSI | Remote SNR | Notes |
|---|---|---|---|---|---|---|
| 11 | 200 m | — | — | −87 to −77 dBm | −2 to +3 dB | building behind, multipath |
| 12 | 20 m | — | — | TBD | TBD | pending |
| 13 | 60 m | — | — | TBD | TBD | pending |

*Winch RSSI not logged at distance — remote display only.*
*200 m pessimistic due to building reflections. Open field expected 5–10 dB better.*

### Full range test — stepper + BLDC running, open flat field, ½ dipoles, vertical

| Distance | Remote RSSI | Remote SNR | Winch RSSI | Winch SNR | Notes |
|---|---|---|---|---|---|
| 0 m | −48 dBm | 11 dB | −33 dBm | 11 dB | |
| 250 m | −88 dBm | 10 dB | −74 dBm | 11 dB | 40 dB jump — possible ground reflection null |
| 400 m | −90 dBm | 10 dB | −77 dBm | 10 dB | |
| 600 m | −98 dBm | 9 dB | −83 dBm | 11 dB | |
| 800 m | −101 dBm | 9 dB | −89 dBm | 10 dB | |
| 1000 m | −104 dBm | 8 dB | −90 dBm | 10 dB | |
| 1000 m | −120 dBm | — | — | — | body covering antenna — packet loss starts here |
| 1200 m | −105 dBm | 6 dB | −91 dBm | 11 dB | |

**Practical sensitivity floor: −120 dBm** (confirmed by body-blocking test at 1000 m)

---

## Summary of all firmware fixes

| Issue | Affected units | Fix | Impact |
|---|---|---|---|
| RF switch pin D5 not driven | Both XIAO units | `setRfSwitchPins(D5, NC)` | +30 dB |
| OCP 240 mA (silent fail, 60 mA actual) | Both XIAO units | Changed to 140 mA | TX power restored |
| OCP never called | Winch ESP32 | `setCurrentLimit(140)` added then disabled | Supply desense discovered |

---

## Final link budget — stepper + BLDC, open field, ½ dipoles

Practical sensitivity floor: −120 dBm · Margin = floor − measured RSSI

| Distance | Remote RSSI | Remote margin | Winch RSSI | Winch margin |
|---|---|---|---|---|
| 0 m | −48 dBm | 72 dB | −33 dBm | 87 dB |
| 250 m | −88 dBm | 32 dB | −74 dBm | 46 dB |
| 600 m | −98 dBm | 22 dB | −83 dBm | 37 dB |
| 1000 m | −104 dBm | 16 dB | −90 dBm | 30 dB |
| 1200 m | −105 dBm | 15 dB | −91 dBm | 29 dB |
| ~1500 m (proj.) | ~−107 dBm | **~13 dB** | ~−93 dBm | **~27 dB** |

**✓ System validated for 1500 m operation with ½ dipole antennas.**
Panel antenna not required. Remote is the limiting side; winch RX has plenty of margin throughout.

*SNR margin = distance from −124 dBm floor. BLDC EMI not yet factored in.*

---

## Open items
- 20 m and 60 m reference tests pending (no BLDC)
- BLDC 8 kW EMI impact unknown — critical test before field deployment
- Hardware fix: decoupling caps on Waveshare SX1262 VDD rail
- New IPEX on remote needs to be redone
- Real open-field 1500 m test pending

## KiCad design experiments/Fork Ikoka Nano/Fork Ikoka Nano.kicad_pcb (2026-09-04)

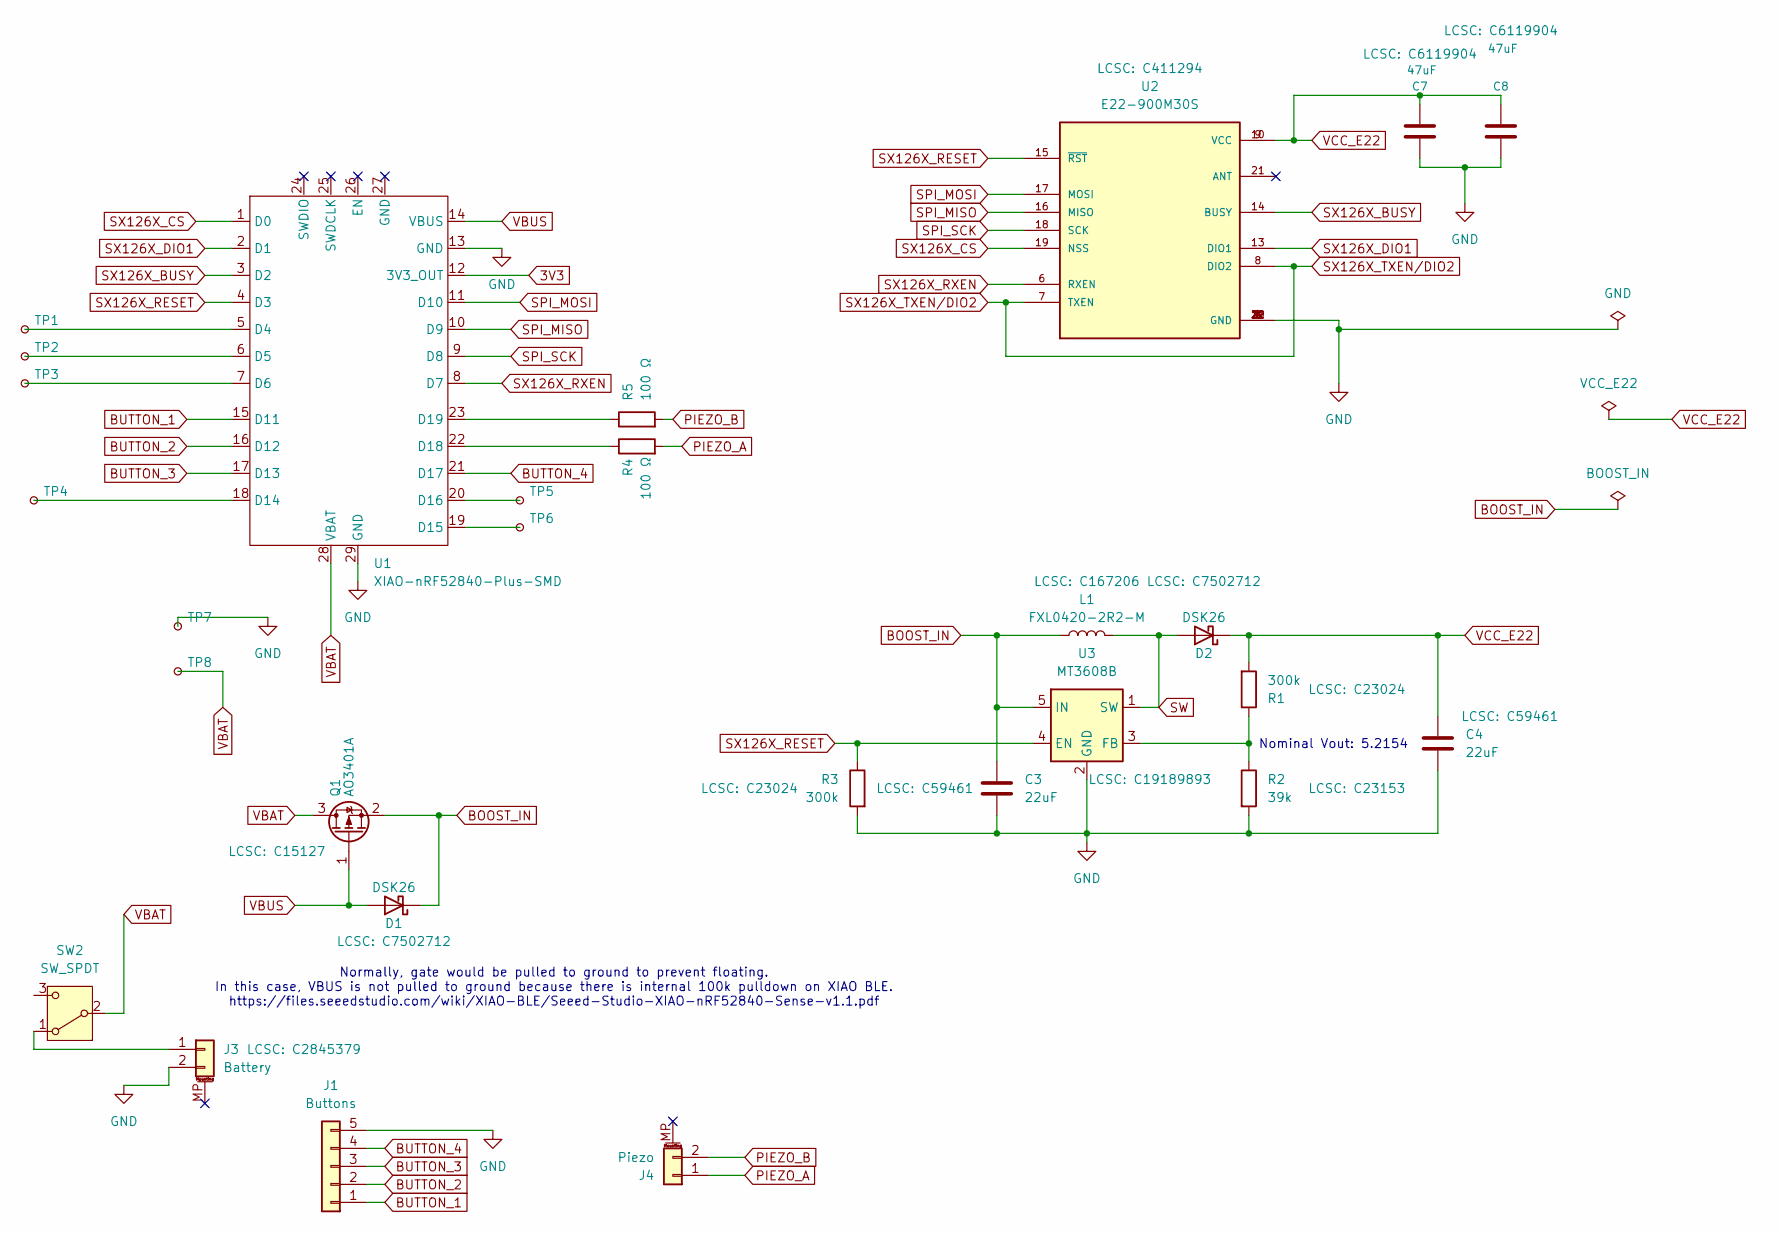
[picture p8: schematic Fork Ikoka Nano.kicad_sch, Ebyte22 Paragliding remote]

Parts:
C3, C4: 22uF; C_0603_1608Metric_Pad1.08x0.95mm_HandSolder; MPN CL10A226MQ8NRNC; LCSC C59461
C7, C8: 47uF; C_0805_2012Metric_Pad1.18x1.45mm_HandSolder; MPN CGA0805X5R476M100MT; LCSC C6119904
D1, D2: DSK26; D_SOD-123F; LCSC C7502712
J1: Buttons; Molex_PicoBlade_53047-0510_1x05_P1.25mm_Vertical
J3: Battery; Molex_PicoBlade_53261-0271_1x02-1MP_P1.25mm_Horizontal; LCSC C2845379
J4: Piezo; SolderWire-0.15sqmm_1x02_P4mm_D0.5mm_OD1.5mm
L1: FXL0420-2R2-M; L_Changjiang_FXL0420; MPN FXL0420-2R2-M; LCSC C167206
Q1: AO3401A; SOT-23; LCSC C15127
R1, R3: 300k; R_0603_1608Metric_Pad0.98x0.95mm_HandSolder; MPN 0603WAF3003T5E; LCSC C23024
R2: 39k; R_0603_1608Metric_Pad0.98x0.95mm_HandSolder; MPN 0603WAF3902T5E; LCSC C23153
R4, R5: 100 Ω; R_0603_1608Metric_Pad0.98x0.95mm_HandSolder; MPN 0603WAF1000T5E; LCSC C22775
SW2: SW_SPDT; SW_SPDT_PCM12
TP1, TP2, TP3, TP4, TP5, TP6: TestPoint_Small; TestPoint_Pad_D1.0mm
TP7, TP8: TestPoint_Small; TestPoint_THTPad_2.0x2.0mm_Drill1.0mm
U1: XIAO-nRF52840-Plus-SMD
U2: E22-900M30S; XCVR_E22-900M30S; PARTREV 1.2; LCSC C411294
U3: MT3608B; SOT-23-6; LCSC C19189893

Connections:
3V3: U1.12 (3V3_OUT)
BOOST_IN: C3.1, D1.1 (K), L1.1, Q1.2 (S), U3.5 (IN)
BUTTON_1: J1.1, U1.15 (D11)
BUTTON_2: J1.2, U1.16 (D12)
BUTTON_3: J1.3, U1.17 (D13)
BUTTON_4: J1.4, U1.21 (D17)
GND: C3.2, C4.2, C7.1, C8.1, J1.5, J3.2, R2.2, R3.2, TP7.1 (1_1), U1.13 (GND), U1.29 (GND), U2.1 (GND), U2.2 (GND), U2.3 (GND), U2.4 (GND), U2.5 (GND), U2.11 (GND), U2.12 (GND), U2.20 (GND), U2.22 (GND), U3.2 (GND); also elsewhere on the board
unnamed: J3.1, SW2.1 (A)
unnamed: TP1.1 (1_1), U1.5 (D4)
unnamed: TP2.1 (1_1), U1.6 (D5)
unnamed: TP3.1 (1_1), U1.7 (D6)
unnamed: TP4.1 (1_1), U1.18 (D14)
unnamed: TP6.1 (1_1), U1.19 (D15)
unnamed: TP5.1 (1_1), U1.20 (D16)
unnamed: R4.1, U1.22 (D18)
unnamed: R5.1, U1.23 (D19)
unnamed: R1.1, R2.1, U3.3 (FB)
PIEZO_A: J4.1, R4.2
PIEZO_B: J4.2, R5.2
SPI_MISO: U1.10 (D9), U2.16 (MISO)
SPI_MOSI: U1.11 (D10), U2.17 (MOSI)
SPI_SCK: U1.9 (D8), U2.18 (SCK)
SW: D2.2 (A), L1.2, U3.1 (SW)
SX126X_BUSY: U1.3 (D2), U2.14 (BUSY)
SX126X_CS: U1.1 (D0), U2.19 (NSS)
SX126X_DIO1: U1.2 (D1), U2.13 (DIO1)
SX126X_RESET: R3.1, U1.4 (D3), U2.15 (~RST), U3.4 (EN)
SX126X_RXEN: U1.8 (D7), U2.6 (RXEN)
SX126X_TXEN/DIO2: U2.7 (TXEN), U2.8 (DIO2)
VBAT: Q1.3 (D), SW2.2 (B), TP8.1 (1_1), U1.28 (VBAT)
VBUS: D1.2 (A), Q1.1 (G), U1.14 (VBUS)
VCC_E22: C4.1, C7.2, C8.2, D2.1 (K), R1.2, U2.9 (VCC), U2.10 (VCC); also elsewhere on the board

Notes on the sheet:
Nominal Vout: 5.2154
Normally, gate would be pulled to ground to prevent floating. In this case, VBUS is not pulled to ground because there is internal 100k pulldown on XIAO BLE. https://files.seeedstudio.com/wiki/XIAO-BLE/Seeed-Studio-XIAO-nRF52840-Sense-v1.1.pdf

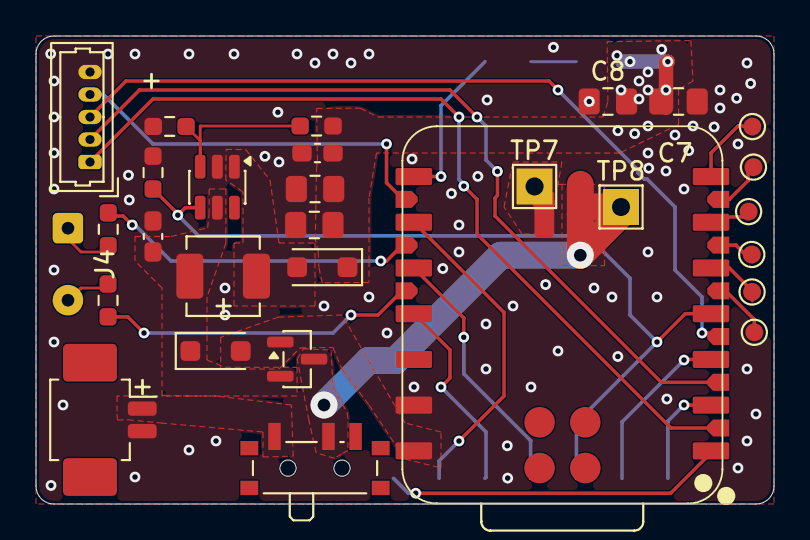
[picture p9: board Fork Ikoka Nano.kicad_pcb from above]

Board: 2 copper layers, 41.0 x 26.0 mm, 30 parts (1 on the bottom side), 31 nets.

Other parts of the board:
C1, C2: 47uF; C_0805_2012Metric_Pad1.18x1.45mm_HandSolder

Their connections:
GND: C1.1, C2.1; also elsewhere on the board
VCC_E22: C1.2, C2.2; also elsewhere on the board

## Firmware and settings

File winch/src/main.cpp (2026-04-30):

#include <M5Stack.h>
#include <Preferences.h>
#include "LoRaComm.h"
#include "Lorastruct.h"
#include "Display.h"
#include "StepperControl.h"
#include "can.h"

// ---- FreeRTOS SPI Mutex ----
#include "freertos/FreeRTOS.h"
#include "freertos/semphr.h"
SemaphoreHandle_t spiMutex; // Global mutex instance

// ---- Globals/State ----
LoRaComm lora;
Display display;
StepperControl stepper(lora);
Preferences prefs;

volatile int lastLoRaRSSI = 0;
volatile float lastLoRaSNR = 0.0;

extern int32_t can_distance;
extern int32_t can_current;
extern int32_t can_temperature;

bool buttonToggled = false;
int32_t lineOutOffset = 0;

bool armLineStop = false;
bool lineStopActivated = false;
const int armLineStopThreshold = 40;
const int lineStopThreshold = 35;

unsigned long lastButtonPressTime = 0;
int buttonCPressCount = 0;

int currentState = 0;

// ---- Amp table (state 0-6, amps per state) ----
int baseCurrents[7] = {0, 20, 40, 60, 100, 120, 140};

// ---- Settings mode ----
bool settingsMode = false;
int settingsSelectedState = 1;
bool forceDisplayRedraw = false;

static unsigned long lastDisplay = 0;  // display only

// ------------ LoRa FreeRTOS Task -------------
void LoRaTask(void *pvParameters) {
    static uint8_t lastCmdSeq = 0;
    static uint8_t metricsSeq = 0;
    static unsigned long lastMetrics = 0;

    for (;;) {
        CmdPacket cmd;

        // 1. Handle incoming commands
        if (lora.receiveCmd(cmd)) {
            currentState = cmd.state;
            lastCmdSeq = cmd.seq;

            // Only allow state change from remote if NOT lineStopActivated
            if (!lineStopActivated) {
                currentState = cmd.state;
            } else {
                Serial.println("[LoRaTask] LineStop active - ignoring remote state change!");
            }

            // Send ACK
            AckPacket ack;
            ack.type = 0x03;
            ack.seq  = cmd.seq;
            ack.pad0 = 0;
            ack.pad1 = 0;
            lora.sendAck(ack);

            // Send metrics immediately after command
            MetricsPacket m;
            m.type        = 0x02;
            m.seq         = metricsSeq++;
            m.lastCmdSeq  = lastCmdSeq;
            m.amps_x10    = can_current * 10;
            m.distance_m  = abs(can_distance - lineOutOffset);
            m.vesc_mV     = 3700; // Replace with real value if available

            // --- State mapping for remote ---
            if (lineStopActivated) {
                m.lineState = 'S';    // Stopped
            } else if (armLineStop) {
                m.lineState = 'A';    // Armed
            } else {
                m.lineState = 'R';    // Ready
            }

            // Debug: print the outgoing packet
            uint8_t* p = (uint8_t*)&m;
            Serial.print("[LoRaTask] Raw metrics bytes (after cmd): ");
            for (int i = 0; i < sizeof(MetricsPacket); ++i) {
                Serial.printf("%02X ", p[i]);
            }
            Serial.println();

            lora.sendMetrics(m);
            lastMetrics = millis();

            // Update RSSI/SNR for local display
            lastLoRaRSSI = lora.getLastRSSI();
            lastLoRaSNR  = lora.getLastSNR();
        }

        // 2. Send periodic metrics
        if (millis() - lastMetrics > METRICS_PERIOD_MS) {
            MetricsPacket m;
            m.type        = 0x02;
            m.seq         = metricsSeq++;
            m.lastCmdSeq  = lastCmdSeq;
            m.amps_x10    = can_current * 10;
            m.distance_m  = abs(can_distance - lineOutOffset);
            m.vesc_mV     = 3700;

            if (lineStopActivated) {
                m.lineState = 'S';
            } else if (armLineStop) {
                m.lineState = 'A';
            } else {
                m.lineState = 'R';
            }

            uint8_t* p = (uint8_t*)&m;
            Serial.print("[LoRaTask] Raw metrics bytes (periodic): ");
            for (int i = 0; i < sizeof(MetricsPacket); ++i) {
                Serial.printf("%02X ", p[i]);
            }
            Serial.println();

            lora.sendMetrics(m);
            lastMetrics = millis();

            // Update RSSI/SNR for local display
            lastLoRaRSSI = lora.getLastRSSI();
            lastLoRaSNR  = lora.getLastSNR();
        }

        vTaskDelay(1); // Always yield to other tasks
    }
}




// ------------ Setup & Main Loop --------------

void setup() {
    Serial.begin(115200);
    Serial.println("Starting setup");

    spiMutex = xSemaphoreCreateMutex();   // CREATE MUTEX FIRST
    Serial.println("Mutex created");

    // Load amp values from NVS (fall back to defaults if not set)
    prefs.begin("winch", true); // read-only
    baseCurrents[1] = prefs.getInt("amp1", 20);
    baseCurrents[2] = prefs.getInt("amp2", 40);
    baseCurrents[3] = prefs.getInt("amp3", 60);
    baseCurrents[4] = prefs.getInt("amp4", 100);
    baseCurrents[5] = prefs.getInt("amp5", 120);
    baseCurrents[6] = prefs.getInt("amp6", 140);
    prefs.end();
    Serial.println("NVS loaded");

    M5.begin();
    Serial.println("M5Stack initialized");

    lora.init();
    Serial.println("LoRa initialized");

    // ---- Start LoRa task on core 1 with high priority ----
    xTaskCreatePinnedToCore(
        LoRaTask,        // Task function
        "LoRaTask",      // Name
        4096,            // Stack size
        NULL,            // Param
        2,               // Priority (2=high, 1=normal, 0=idle)
        NULL,            // Task handle (not used)
        1                // Core 1 (best for ESP32, keeps WiFi/BT on core 0)
    );
    Serial.println("LoRaTask started");

    display.init();
    Serial.println("Display initialized");

    stepper.setup();
    Serial.println("Stepper initialized");

    can_setup();
    Serial.println("CAN initialized");
}

void loop() {
    // --- Button B: Toggle settings mode ---
    if (M5.BtnB.wasPressed()) {
        if (settingsMode) {
            // Exit settings: save all amp values to NVS
            prefs.begin("winch", false);
            prefs.putInt("amp1", baseCurrents[1]);
            prefs.putInt("amp2", baseCurrents[2]);
            prefs.putInt("amp3", baseCurrents[3]);
            prefs.putInt("amp4", baseCurrents[4]);
            prefs.putInt("amp5", baseCurrents[5]);
            prefs.putInt("amp6", baseCurrents[6]);
            prefs.end();
            settingsMode = false;
            forceDisplayRedraw = true;
            display.init(); // restore static UI elements
            Serial.println("Settings saved, exiting settings mode");
        } else {
            settingsMode = true;
            settingsSelectedState = 1;
            display.updateSettingsDisplay(settingsSelectedState, baseCurrents);
            Serial.println("Entering settings mode");
        }
    }

    // --- Button C: line reset / deactivate (normal mode only) ---
    if (!settingsMode && M5.BtnC.wasPressed()) {
        unsigned long currentTime = millis();
        if (currentTime - lastButtonPressTime < 500) {
            buttonCPressCount++;
        } else {
            buttonCPressCount = 1;
        }
        lastButtonPressTime = currentTime;

        if (buttonCPressCount == 2) {
            lineStopActivated = false;
            armLineStop = false;
            Serial.println("LineStop deactivated");
        } else {
            lineOutOffset = can_distance;
            Serial.println("LineOut reset");
        }
    }

    // --- Calculate adjusted LineOut value ---
    int32_t adjustedLineOut = abs(can_distance - lineOutOffset);

    // --- Arm/Trigger line stop (always runs) ---
    if (!armLineStop && adjustedLineOut > armLineStopThreshold) {
        armLineStop = true;
        Serial.println("LineStop armed");
    }
    if (armLineStop && !lineStopActivated && adjustedLineOut < lineStopThreshold) {
        lineStopActivated = true;
        Serial.println("LineStop activated");
    }

    // --- Failsafe: Force STOP if lineStopActivated ---
    if (lineStopActivated) {
        currentState = 0;
    }

    // --- Settings mode: navigation and display ---
    if (settingsMode) {
        // Button A: cycle selected state 1→2→3→4→5→6→1
        if (M5.BtnA.wasPressed()) {
            settingsSelectedState = (settingsSelectedState % 6) + 1;
            display.updateSettingsDisplay(settingsSelectedState, baseCurrents);
        }

        // Button C short press: +10A, long press: -10A
        static unsigned long btnCSettingsStart = 0;
        if (M5.BtnC.wasPressed()) {
            btnCSettingsStart = millis();
        }
        if (M5.BtnC.wasReleased()) {
            if (millis() - btnCSettingsStart > 500) {
                // Long press: decrement
                baseCurrents[settingsSelectedState] -= 10;
                if (baseCurrents[settingsSelectedState] < 0) baseCurrents[settingsSelectedState] = 200;
            } else {
                // Short press: increment
                baseCurrents[settingsSelectedState] += 10;
                if (baseCurrents[settingsSelectedState] > 200) baseCurrents[settingsSelectedState] = 0;
            }
            display.updateSettingsDisplay(settingsSelectedState, baseCurrents);
        }

    } else {
        // --- Normal display dirty-check ---
        static int lastDisplayedState = -1;
        static int lastDisplayedLineOut = -1;
        static int lastDisplayedCurrent = -9999;
        static bool lastDisplayedLineStopArmed = false;
        static bool lastDisplayedLineStopActivated = false;
        static int lastDisplayedTemperature = -9999;
        static int lastDisplayedRSSI = 12345;    // impossible value to force update first loop
        static float lastDisplayedSNR = 12345.0; // impossible value to force update first loop

        if (
            forceDisplayRedraw ||
            currentState != lastDisplayedState ||
            adjustedLineOut != lastDisplayedLineOut ||
            can_current != lastDisplayedCurrent ||
            armLineStop != lastDisplayedLineStopArmed ||
            lineStopActivated != lastDisplayedLineStopActivated ||
            can_temperature != lastDisplayedTemperature ||
            lastLoRaRSSI != lastDisplayedRSSI ||
            lastLoRaSNR != lastDisplayedSNR
        ) {
            display.updateDisplay(
                currentState,
                lastLoRaRSSI,
                lastLoRaSNR,
                adjustedLineOut,
                can_current,
                armLineStop,
                lineStopActivated,
                can_temperature
            );
            lastDisplayedState = currentState;
            lastDisplayedLineOut = adjustedLineOut;
            lastDisplayedCurrent = can_current;
            lastDisplayedLineStopArmed = armLineStop;
            lastDisplayedLineStopActivated = lineStopActivated;
            lastDisplayedTemperature = can_temperature;
            lastDisplayedRSSI = lastLoRaRSSI;
            lastDisplayedSNR = lastLoRaSNR;
            forceDisplayRedraw = false;
        }

        // --- Button A: Manual toggle stepper (normal mode only) ---
        if (M5.BtnA.wasPressed()) {
            buttonToggled = !buttonToggled;
        }
    }

    // --- Stepper logic (always runs) ---
    if (buttonToggled) {
        stepper.runStepper();
    } else {
        if (currentState == 0) {
            stepper.stopAndCenter();
        } else {
            stepper.runStepper();
        }
    }
    stepper.update();

    // --- CAN (always runs) ---
    can_send_message();
    can_receive_message();

    M5.update();
    delay(5); // keep loop responsive
}

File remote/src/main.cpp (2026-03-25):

#include <Arduino.h>
#include <SPI.h>
#include <RadioLib.h>
#include <Button2.h>
#include "utilities.h"
#include "lorastruct.h"
#include "buzzer.h"
#include "ble_interface.h"

#define DEBUG
#ifdef DEBUG
  #define DBG(x)          Serial.println(x)
  #define DBGF(fmt, ...)  Serial.printf((fmt "\n"), ##__VA_ARGS__)
#else
  #define DBG(x)
  #define DBGF(fmt, ...)
#endif

// ─── LoRa ────────────────────────────────────────────────────────────────────
Module    radioMod(LORA_CS_PIN, LORA_DIO1_PIN, LORA_RST_PIN, LORA_BUSY_PIN, SPI);
SX1262    lora(&radioMod);
static bool loraReady = false;

volatile bool radioIRQ = false;
void dio1ISR() { radioIRQ = true; }   // no IRAM_ATTR on nRF52840

// ─── Packet loss tracking (20-second window, same as T3) ─────────────────────
static uint8_t  lastMetricsSeq          = 0;
static uint16_t metricsReceivedThisWindow = 0;
static uint16_t metricsLostThisWindow   = 0;
static float    packetLossPercent       = 0.0f;
static uint32_t windowStartTime        = 0;
const  uint32_t PACKET_LOSS_WINDOW_MS  = 20000;

// ─── State tracking (T3 convention) ──────────────────────────────────────────
uint8_t txSeq          = 0;
uint8_t awaitingSeq    = 0;
uint8_t desiredState   = 0;
uint8_t confirmedState = 0;

volatile bool metricsDirty = false;
uint32_t buttonEventCounter = 0;

// ─── DOWN button state ────────────────────────────────────────────────────────
struct SimpleButtonState {
  bool     lastRawState;
  bool     lastStableState;
  uint32_t lastChangeTime;
  uint32_t pressStartTime;
  uint32_t lastClickTime;
  uint32_t clickCount;
  bool     isPressed;
  bool     pressConsumed;
} downBtn = {true, true, 0, 0, 0, 0, false, false};

const uint32_t SIMPLE_DEBOUNCE_MS  = 20;
const uint32_t MIN_PRESS_MS        = 30;
const uint32_t DOUBLE_CLICK_WINDOW = 300;
const uint32_t MULTI_CLICK_WINDOW  = 800;

// ─── UP button ────────────────────────────────────────────────────────────────
Button2 btnUp(BTN_UP_PIN);

// ─── Forward declarations ─────────────────────────────────────────────────────
bool sendCmd(uint8_t st);
void processDownButton();
void processMetricsPacket(const MetricsPacket* m);

// ─── Remote battery (XIAO nRF52840) ──────────────────────────────────────────
// PIN_VBAT  = 32 = P0.31  battery sense (1MΩ:510kΩ divider output)
// pin 14    = P0.14       enable divider, active LOW
// pin 23    = P0.23       charge state, LOW = charging
// pin 22    = P0.22       charge current, LOW=100mA HIGH=50mA
#define VBAT_ENABLE_PIN  14   // P0.14, OUTPUT LOW to connect divider
#define CHG_STATE_PIN    23   // P0.23, INPUT, LOW = charging
#define CHG_CURR_PIN     22   // P0.22, OUTPUT, LOW=100mA

float readRemoteBatteryVoltage() {
  // 10-bit ADC, 3.3V ref, 1MΩ:510kΩ divider
  int raw = analogRead(PIN_VBAT);
  return raw * 3.3f / 1023.0f * (1510.0f / 510.0f);
}

int voltageToPercent(float v) {
  if (v >= 4.20f) return 100;
  if (v <= 3.40f) return 0;
  return (int)((v - 3.40f) / (4.20f - 3.40f) * 100.0f);
}

// ─── MetricsPacket handler (called from both sendCmd loop and main loop) ──────
void processMetricsPacket(const MetricsPacket* m) {
  uint32_t now = millis();

  // Initialise window on first packet
  if (metricsReceivedThisWindow == 0) {
    windowStartTime = now;
    lastMetricsSeq  = m->seq;
  }

  // Count gaps as lost packets
  if (metricsReceivedThisWindow > 0) {
    uint8_t expected = lastMetricsSeq + 1;
    if (m->seq != expected) {
      metricsLostThisWindow += (m->seq - expected) & 0xFF;
    }
  }
  metricsReceivedThisWindow++;
  lastMetricsSeq = m->seq;

  // Recalculate loss at end of each window
  if (now - windowStartTime >= PACKET_LOSS_WINDOW_MS) {
    uint16_t total = metricsReceivedThisWindow + metricsLostThisWindow;
    packetLossPercent = (total > 0) ? (metricsLostThisWindow * 100.0f / total) : 0.0f;
    metricsReceivedThisWindow = 0;
    metricsLostThisWindow     = 0;
    windowStartTime           = now;
  }

  bleInterface.setLineState(m->lineState);
  bleInterface.setMetrics(m->distance_m, m->amps_x10 / 10.0f, m->vesc_mV / 1000.0f);
  bleInterface.setSignalQuality(lora.getRSSI(), lora.getSNR(), packetLossPercent);
  metricsDirty = true;
}

// ─── sendCmd() ── immediate BLE feedback, then LoRa ACK/retry if radio ready ─
bool sendCmd(uint8_t st) {
  uint8_t oldState = confirmedState;

  // Always give instant audio + BLE feedback regardless of LoRa state
  confirmedState = st;
  if (confirmedState == 0 && oldState == 0) buzzer.playStateChange(1, 0);
  else                                       buzzer.playStateChange(oldState, confirmedState);
  bleInterface.setState(confirmedState);
  bleInterface.sendTelemetry();

  if (!loraReady) {
    DBGF("[CMD] LoRa offline — local confirm only  %u→%u", oldState, st);
    return true;
  }

  // ─── LoRa ACK/retry loop ─────────────────────────────────────────────────
  confirmedState = oldState;  // revert until ACK confirms
  bleInterface.setState(confirmedState);

  CmdPacket pkt{};
  pkt.type  = 0x01;
  pkt.seq   = ++txSeq;
  pkt.state = st;

  DBGF("[CMD] %u→%u seq:%u", oldState, st, pkt.seq);

  for (uint8_t attempt = 1; attempt <= CMD_MAX_RETRIES; ++attempt) {
    DBGF("[CMD] attempt %u/%u", attempt, CMD_MAX_RETRIES);

    lora.transmit(reinterpret_cast<uint8_t*>(&pkt), sizeof(pkt));
    lora.startReceive();
    awaitingSeq = pkt.seq;
    uint32_t deadline = millis() + ACK_TIMEOUT_MS;

    while (awaitingSeq && (int32_t)(millis() - deadline) < 0) {
      if (radioIRQ) {
        radioIRQ = false;
        uint8_t buf[16];
        size_t  len = sizeof(buf);

        if (lora.readData(buf, len) == RADIOLIB_ERR_NONE && len) {
          if (buf[0] == 0x03 && len >= sizeof(AckPacket)) {
            auto* ack = reinterpret_cast<AckPacket*>(buf);
            if (ack->seq == awaitingSeq) {
              awaitingSeq    = 0;
              confirmedState = st;
              if (confirmedState == 0 && oldState == 0) buzzer.playStateChange(1, 0);
              else                                       buzzer.playStateChange(oldState, confirmedState);
              bleInterface.setState(confirmedState);
              bleInterface.sendTelemetry();
              DBGF("[CMD] ACK  confirmed:%u", confirmedState);
              return true;
            }
          } else if (buf[0] == 0x02 && len >= sizeof(MetricsPacket)) {
            processMetricsPacket(reinterpret_cast<MetricsPacket*>(buf));
          }
        }
        lora.startReceive();
      }
      buzzer.update();
    }

    if (!awaitingSeq) return true;
    DBGF("[CMD] timeout attempt %u", attempt);
  }

  DBGF("[CMD] FAILED — winch unreachable");
  bleInterface.setState(confirmedState);
  bleInterface.sendTelemetry();
  return false;
}
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

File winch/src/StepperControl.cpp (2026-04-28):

#include "StepperControl.h"

StepperControl::StepperControl(LoRaComm& loraComm) : lora(loraComm) {}

void StepperControl::setup() {
    M5.begin();
    Serial.begin(115200);  // Initialize serial monitor

    // Configure the PWM settings
    ledcSetup(pwmChannel, pwmFrequency, pwmResolution);
    ledcAttachPin(pwmPin, pwmChannel);
    ledcWrite(pwmChannel, pwmValue);  // Set initial PWM duty cycle

    // Setup other GPIO pins
    pinMode(runStepperPin, OUTPUT);
    pinMode(dirStepperPin, OUTPUT);
    pinMode(limitSwitchPin, INPUT_PULLUP);
}

void StepperControl::runStepper() {
    if (motorState != RUNNING) {
        motorState = RUNNING;
        motorRunning = true;
        digitalWrite(runStepperPin, HIGH);
    }

    if (checkLimitSwitch()) {
        toggleMotorDirection();
    }
}

void StepperControl::stopAndCenter() {
    if (motorRunning) {
        motorRunning = false;
        motorState = CENTERING_TO_LIMIT;
        digitalWrite(runStepperPin, HIGH);  // Ensure motor is running
    }
}

void StepperControl::update() {
   // Serial.print("MotorState: ");
    //Serial.println(motorState);

    // Declare the variables outside the switch statement
    unsigned long currentTime = millis();
    unsigned long elapsedTime = 0;

    switch (motorState) {
        case RUNNING:
            if (checkLimitSwitch()) {
               // Serial.println("Limit switch hit in RUNNING state");
                toggleMotorDirection();
            }
            break;

        case CENTERING_TO_LIMIT:
            if (checkLimitSwitch()) {
               // Serial.println("Limit switch hit in CENTERING_TO_LIMIT state");
                toggleMotorDirection();
                motorState = CENTERING_BACK;
                centeringStartTime = millis();
                //Serial.print("Centering Start Time: ");
                //Serial.println(centeringStartTime);
            }
            break;

        case CENTERING_BACK:
            elapsedTime = currentTime - centeringStartTime;
           // Serial.print("ElapsedTime: ");
           // Serial.println(elapsedTime);
            if (elapsedTime < additionalRunTime) {
                if (checkLimitSwitch()) {
                    //Serial.println("Limit switch hit in CENTERING_BACK state");
                    toggleMotorDirection();
                }
            } else {
                motorState = IDLE;
                //Serial.println("Centering completed, setting motor to IDLE");
                digitalWrite(runStepperPin, LOW);
                motorRunning = false;
            }
            break;

        case IDLE:
        default:
            // Do nothing
            break;
    }
}


void StepperControl::updatePWM(int value) {
    pwmValue = value;
    ledcWrite(pwmChannel, pwmValue);
}

void StepperControl::setPwmValue(int value) {
    updatePWM(value);
}

void StepperControl::toggleMotorDirection() {
    motorDirection = !motorDirection;
    digitalWrite(dirStepperPin, motorDirection ? HIGH : LOW);
   // Serial.print("Motor direction toggled to: ");
   // Serial.println(motorDirection ? "Forward" : "Backward");
}

bool StepperControl::checkLimitSwitch() {
    static bool lastSwitchState = HIGH;
    bool currentSwitchState = digitalRead(limitSwitchPin);
    
    if (currentSwitchState != lastSwitchState && currentSwitchState == LOW) {
        if (millis() - lastDebounceTime > debounceDelay) {
            lastDebounceTime = millis();
            lastSwitchState = currentSwitchState;
           // Serial.println("Limit switch triggered");
            return true;
        }
    }
    lastSwitchState = currentSwitchState;
    return false;
}

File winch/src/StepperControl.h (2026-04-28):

#ifndef STEPPER_CONTROL_H
#define STEPPER_CONTROL_H

#include <M5Stack.h>
#include "LoRaComm.h"

class StepperControl {
public:
    StepperControl(LoRaComm& loraComm);
    void setup();
    void runStepper();
    void stopAndCenter();
    void update();  // Non-blocking update function
    void setPwmValue(int value);  // New function to adjust PWM value

private:
    enum MotorState { IDLE, RUNNING, CENTERING_TO_LIMIT, CENTERING_BACK };
    MotorState motorState = IDLE;

    LoRaComm& lora;  // Reference to LoRaComm instance
    const int pwmPin = 25;
    const int runStepperPin = 22;
    const int dirStepperPin = 21;
    const int limitSwitchPin = 35;

    int pwmFrequency = 20000;  // SPEED 
    const int pwmChannel = 0;
    const int pwmResolution = 8;  // 8-bit resolution

    int pwmValue = 95;   //SPEED SETTING 0-255
    bool motorRunning = false;
    bool motorDirection = false;  // False for backward, true for forward

    unsigned long lastDebounceTime = 0;  // the last time the output pin was toggled
    const unsigned long debounceDelay = 50;  // the debounce time; increase if the output flickers

    unsigned long additionalRunTime = 7500;  // Time to run after hitting limit switch (in milliseconds)
    unsigned long centeringStartTime = 0;  // Start time for centering run

    void updatePWM(int value);
    void toggleMotorDirection();
    bool checkLimitSwitch();
};

#endif

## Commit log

2026-01-10 Add files via upload
    wrong folder
    [main.cpp]
2026-03-12 Add Xiao nRF52840 firmware (Phase 1: BLE + buttons + buzzer)
    [ble_interface.cpp, lorastruct.h, main.cpp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]
2026-03-12 Fix remote battery reading for XIAO nRF52840
    - Use PIN_VBAT (Arduino 32 = P0.31) as battery sense pin
    - Use Arduino 14 (P0.14) as divider enable, active LOW
    - Fix ADC formula: 10-bit (1023) with 1MΩ:510kΩ divider (×2.961)
    - Add charge state detection on Arduino 23 (P0.23), LOW = charging
    - Add charge current control on Arduino 22 (P0.22), LOW = 100mA
    - Add [BAT] debug output with voltage, percent and charging state
    [main.cpp]
2026-03-25 Fix LoRa RF switch, OCP, and add state indicator buzzer
    LoRa fixes (major signal improvement, ~30dB recovered):
    - Add setRfSwitchPins(LORA_RXEN_PIN, RADIOLIB_NC) — D5 RF switch on Wio
    SX1262 was never driven, leaving RX path nearly dead
    - Fix LORA_CURRENT_LIMIT_MA 240->140mA (RadioLib max; silent fail left
    OCP at 60mA, tripping on every TX at 22dBm)
    Buzzer:
    - Add state indicator sequencer: N beeps/sec while in state N (1-6)
    - Updated base frequencies to 2000-3600Hz range with resonant peak at state 4
    - Enable high drive mode on buzzer pin for more volume
    - Add setStateIndicator() call in loop()
    [lorastruct.h, main.cpp]
2026-03-25 Add XiaoWinchSim diagnostic tool and antenna test log
    XiaoWinchSim: XIAO nRF52840 + Wio SX1262 firmware that simulates the
    winch LoRa side. Receives CmdPackets, sends AckPackets and periodic
    MetricsPackets with simulated telemetry. Used to isolate antenna and
    signal issues without needing the real winch hardware.
    antenna_tests.md: Full signal test log from development session including:
    - Discovery and fix of RF switch pin D5 not driven (~30dB recovery)
    - OCP silent failure fix (240->140mA)
    - Waveshare SX1262 supply desense investigation
    - Distance tests at 10/200m with/without BLDC
    - Link budget projections to 1500m target range
    [lorastruct.h, main.cpp, utilities.h]
2026-03-25 Add CLAUDE.md with full project context
    Captures hardware config, pin mappings, packet protocol, all firmware
    fixes applied, signal quality reference numbers, link budget to 1500m,
    and open hardware items. Loads automatically in Claude Code sessions.
2026-03-30 Add full range test results — system validated to 1500m
    Stepper + BLDC running, open flat field, half-dipoles both ends.
    Measured to 1200m, projected to 1500m. Practical sensitivity floor
    confirmed at -120 dBm via body-blocking test at 1000m.
    Remote side: ~13dB margin at 1500m. Winch side: ~27dB margin.
    Panel antenna not required.
2026-04-21 Add XC Tracer Mini V BLE connection with Speed and ALT display
    - Second BLE connection to XCT device (service 0xFFE0, char 0xFFE1)
    - LXWP0 NMEA sentence parser: airspeed km/h (field 2), baro alt m (field 3)
    - Two new medium cards in UI: Speed (km/h) and ALT (m)
    - Middle column expanded from 2x2 to 2x3 grid to fit new cards
    - Separate Connect/Disconnect XCT buttons and status in header
2026-04-21 Fix XCT parser: speed from GPRMC (knots->km/h), ALT from LXWP0
    - Replace LXWP0-only parser with NMEA sentence dispatcher
    - $GPRMC field[7] * 1.852 -> Speed km/h (only when status=A/fix valid)
    - $LXWP0 field[3] -> ALT metres (barometric, available after GPS fix)
    - Also handles $GNRMC (multi-constellation variant)
2026-04-21 Fix XCT: GPS altitude from GPGGA, speed from GPRMC
    - ALT now reads GPGGA field[9] (GPS altitude MSL) when fix quality > 0
    - Speed reads GPRMC field[7] (knots * 1.852) when status = A
    - Removes LXWP0 altitude (baro, pre-fix offset was misleading)
    - Also handles GNGGA/GNRMC multi-constellation variants
2026-04-21 v1.2: Switch ALT source to LXWP0 baro (always available, 3Hz update)
    GPGGA GPS altitude requires fix and only updates 1Hz.
    LXWP0 baro altitude is available immediately and updates ~3x/sec,
    making it better for winch launch height tracking. Offset (~-130m)
    is constant (local pressure vs standard atmosphere) so relative
    climb is accurate. Relabelled card to 'Baro Alt'.
2026-04-21 v1.4: Single Connect All button + auto-reconnect on page load
    - Replace 4 buttons with Connect All / Disconnect All
    - Auto-reconnect on page load using getDevices() for previously
    permitted devices (no scan dialog required)
    - Refactored connect logic into connectToDevice() / connectToXCT()
    shared by both manual scan and auto-reconnect paths
2026-04-21 v1.5: Auto-connect on load, status dots, Connect button only when needed
    - Page loads and silently reconnects both devices via getDevices()
    - Green/red dot indicators for Winch and XCT connection state
    - Connect button only appears when one or both devices are not connected
    - First-ever use: tap Connect -> two scan dialogs -> remembered forever
2026-04-21 v1.6: Add CSV flight logging (Start Log / Stop Log button)
    - Green Start Log button in header, turns red when active
    - Logs one row per second: timestamp + all winch + XCT values
    - Stop Log triggers automatic CSV download named winch_YYYY-MM-DD_HH-MM-SS.csv
    - Columns: timestamp, state, line_distance_m, line_state, amps_A, temp_C,
    rssi_dBm, snr_dB, lost_pct, winch_bat_pct, remote_bat_pct,
    winch_voltage_V, speed_kmh, gps_alt_m
2026-04-21 v1.7: Enhanced flight log with derived metrics and summary block
    New CSV columns:
    - elapsed_s: seconds since log start
    - alt_gain_m: height above launch baseline (auto-zeroed)
    - climb_rate_ms: vertical speed (m/s)
    - line_speed_ms: rate of line payout (m/s)
    - power_kW: instantaneous power (amps x voltage)
    - energy_Wh: cumulative energy used
    Summary block at top of CSV:
    - Duration, max height gained, max speed, max climb rate
    - Max amps, max power, total energy, efficiency (m/Wh), max line out
    Also: removed debug log bar and xctRaw span (no longer needed)
2026-04-28 Restructure into monorepo
    - remote/ Xiao remote firmware
    - winch/ ESP winch controller (from 868-ParaWinch)
    - sim/ XiaoWinchSim dev helper
    - archive/ ItsyBitsy (unused)
    - docs/ antenna_tests.md spec
    - root phone app (GitHub Pages)
2026-04-28 Add project documents to docs/
    [2026-04-27_11-48-02.csv, 2026-04-27_13-59-08.csv, 2026-04-27_14-14-21.csv]
2026-04-28 Add battery.md to docs
2026-04-30 Phase 1: Move amp control from VESC Lisp to M5Stack
    - Lisp: remove handle-state lookup table; receive target amps as int16
    over CAN instead of state int8; add 3s watchdog (zeros current on
    CAN timeout)
    - CAN: send_custom_can_message now sends int16 amps big-endian (2 bytes)
    - main: add baseCurrents[7] table with NVS persistence; add settings
    mode on Button B — navigate with A, adjust with C (+/-10A), save on exit
    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
2026-04-30 Add tow calculator and live force estimate to web app (v1.8)
    - Calculator subpage (purple Calc button): sliders for current and
    line out, gauges for line pull / speed / drum diameter, safe/warn/
    danger status strip with max safe amps
    - Main screen: live ~kg force estimate below amps value, coloured
    green/orange/red vs 80 kg pilot weight limit
    - Physics: drum model updated to 150 mm empty / 290 mm full;
    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
2026-09-04 Add Fork Ikoka Nano KiCad project, remove old ebyteremote experiment
    Migrated the working Fork Ikoka Nano copy into experiments/ (deduplicated
    from a nested double-copy) and registered OPL_Kicad_Library as a proper
    submodule. Removed the ebyteremote/ParaWinchRemote experiment, no longer
    needed. Added a new towmonitor spec doc.
    [E22-900M30S--3DModel-STEP-418109.STEP, E22-900M30S.step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]
